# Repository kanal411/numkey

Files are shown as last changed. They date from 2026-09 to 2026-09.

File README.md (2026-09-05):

# Numkey
Functional external numerical keypad using only one keyboard switch on a H-bot kinematics.

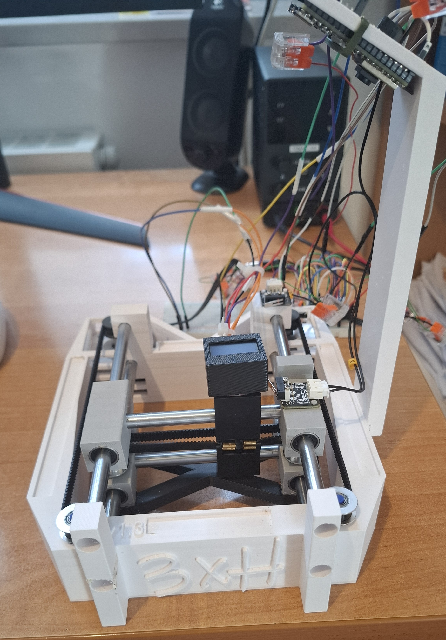
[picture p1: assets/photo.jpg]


## Features
- calibration process
- fully functional numlock
- H-bot kinematic
- sacrificial component

## How it works
An ESP32-S3 captures a photo of where your finger is, and then sends it to the connected PC via USB C. Then, a local neural network detects your finger, transforms its location on the photo to into coordinates above the device and moves the keyboard switch to the position of corresponding numpad key and updates the screen. When the ESP32 detects that the switch is pressed it sends that information to PC and a python script emulates keyboard inputs.

## Purpose
Main purpose of this project was for me to learn more about neural networks, controlling stepper motors and learning about different kinematics.

## Requirements
- Windows PC
- python 3
- arduino IDE (or other software to upload firmware to ESP32)

## How to make
### How to print:
  1. [`chassis.stl`](./models/chassis.stl) - ensure that chosen filament can withstand stepper motors temperatures, use low layer height/variable layer height, use organic supports.
  2. [`carriages.stl`](./models/carriages.stl) - use low layer height/variable layer height.
  3. [`sacrificial.stl`](./models/sacrificial.stl) - exact settings may need tuning for different printers, don't use more than 2 wall loops, use low infill (<=5%).
  4. [`rest.stl`](./models/rest.stl) - no supports.
### How to assemble:
  1. Assemble the parts as shown in [`assembly.mp4`](./assets/assembly.mp4).
  2. Install the timing belt.
  3. Upload [`ESP32_firmware.ino`](./code/ESP32_firmware.ino) to ESP32-S3.
  4. Connect all the wires accordingly to [`wiring.txt`](./assets/wiring.txt).
### How to use:
  1. Download all the files from [`code/`](./code/).
  2. Make sure that you have all of the packages listed in [`req.txt`](./req.txt).
  3. Plug the ESP32 into the PC via USB.
  4. Run [`main_code.py`](./code/main_code.py)

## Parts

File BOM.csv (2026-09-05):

item | quantity | price | note
ESP32-S3 + OV2640 | 1 | ~16$
0.96 OLED I2C 128x64 | 1 | ~2.5$
DR8825 | 2 | ~2$ x 2 | I recommend to buy it with radiator
LM8UU | 10 | ~1.3$ x 10
linear rail 8mm | 808cm | ~10$ | 2x 150cm, 2x 168cm, 2x 86cm
GT2 6mm timing pulley 5mm bore | 2 | ~2$ x2
GT2 6mm smooth pulley 5mm bore | 4 | ~2$ x4
GT2 6mm timing belt | 120cm | ~3$ | Exact lenght may vary
timing belt clamp | 2 | ~0.5$ x2
NEMA17 stepper motor | 2 | ~15$ x2 | I took them from ender 3 v2, if you use off-shelf then you have to buy a timing pulley for it
limit switch | 2 | ~2$ x2 | I took them from ender 3 v2
total |  | ~95.5$

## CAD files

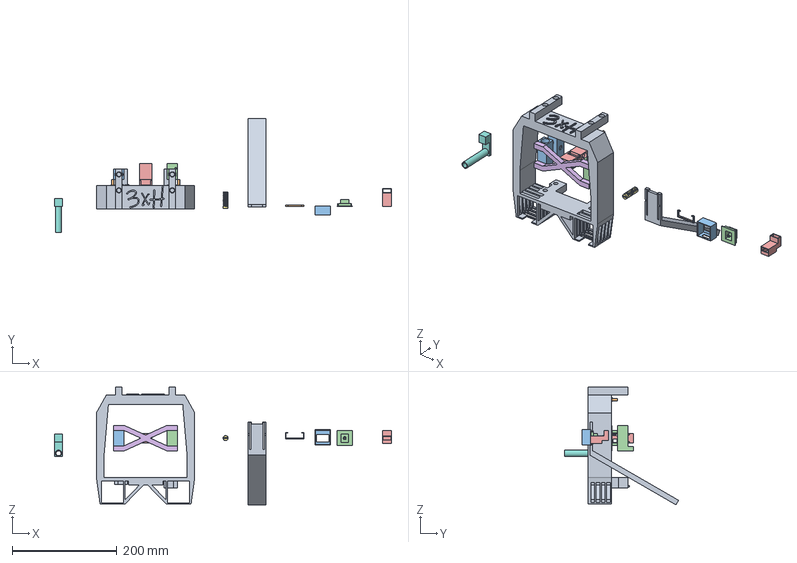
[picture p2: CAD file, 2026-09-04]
models/full_cad.step
644.1 x 218.3 x 225.0 mm

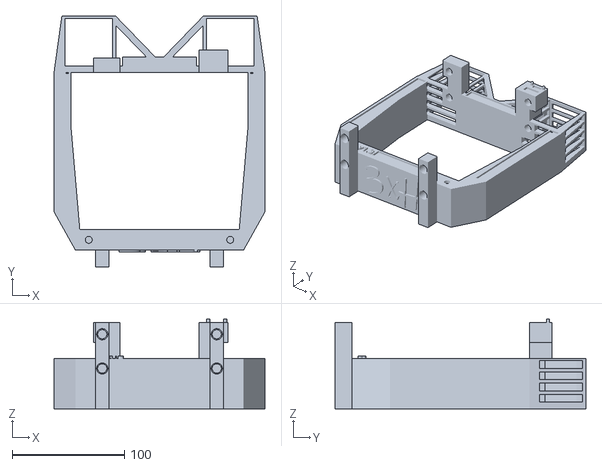
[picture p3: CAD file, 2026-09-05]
models/chassis.stl
188.0 x 223.2 x 80.0

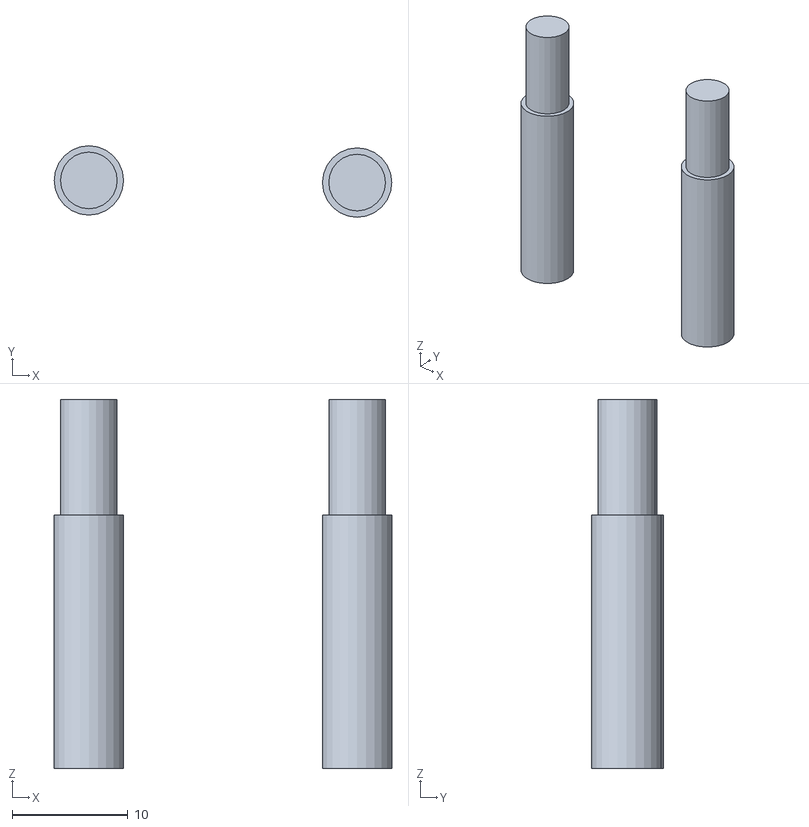
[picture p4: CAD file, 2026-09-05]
models/sacrificial.stl
29.2 x 6.19 x 31.9

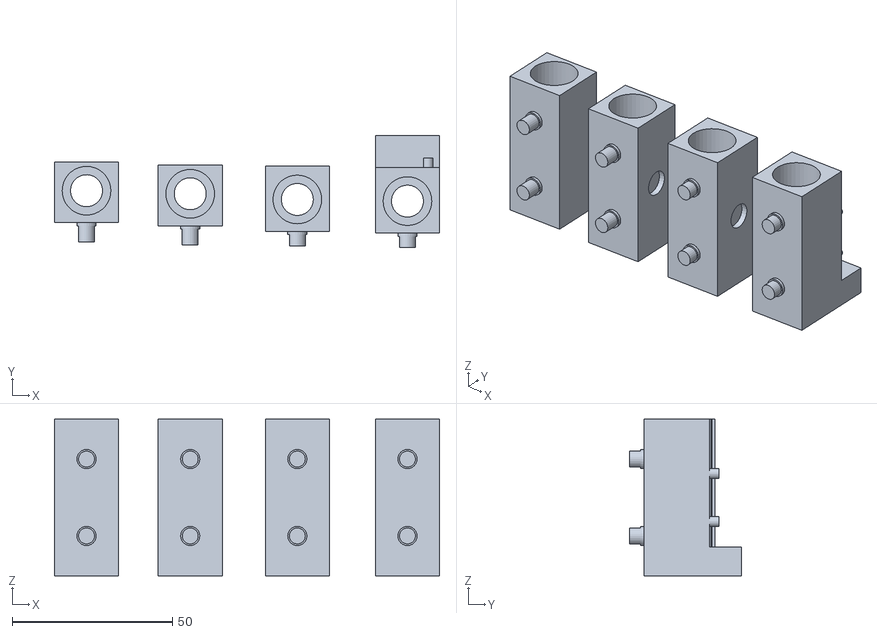
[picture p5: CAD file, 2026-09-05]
models/carriages.stl
120.2 x 35.0 x 49.0

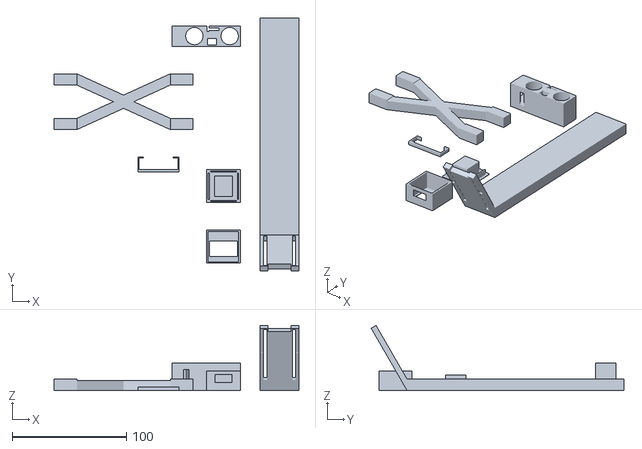
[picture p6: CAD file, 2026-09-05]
models/rest.stl
214.8 x 221.5 x 57.1

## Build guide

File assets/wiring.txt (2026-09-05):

OLED SDA - GPIO 48
OLED SCL - GPIO 47
X safety interlock - GPIO 14
Y safety interlock - GPIO 21
motor A dir - GPIO 2
motor A step - GPIO 1
motor B dir - GPIO 42
motor B step - GPIO 41

motor A/B EN - GND from ESP32
motor A/B M0 - 3.3V from ESP32
motor A/B M1 - 3.3V from ESP32
motor A/B M2 - 3.3V from ESP32
motor A/B RST - 3.3V from ESP32
motor A/B SLP - 3.3V from ESP32
motor A/B VMOT - 12V
motor A/B GN MOT - 12V supply GND
motor A/B B2 - stepper motor
motor A/B B1 - stepper motor
motor A/B A1 - stepper motor
motor A/B A2 - stepper motor
motor A/B GND LOGIC -ESP32 GND

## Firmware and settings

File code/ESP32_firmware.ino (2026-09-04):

#include "esp_camera.h"
#include "esp_task_wdt.h"
#include <Wire.h>
#include <Adafruit_GFX.h>
#include <Adafruit_SSD1306.h>

#define OLED_W    128
#define OLED_H    64
#define OLED_ADDR 0x3C
#define OLED_SDA  48
#define OLED_SCL  47

Adafruit_SSD1306 display(OLED_W, OLED_H, &Wire, -1);
bool oledReady = false;

#define MAX_TEXT_LEN 128

#define BUTTON_PIN          40
#define BUTTON_ACTIVE_HIGH  true
#define BUTTON_DEBOUNCE_MS  30

#define USE_AUTO_EXPOSURE   false
#define EXPOSURE_VALUE      130
#define GAIN_VALUE          12

static const uint8_t SYNC0 = 0xA5;
static const uint8_t SYNC1 = 0x5A;
static const uint8_t TYPE_FRAME    = 0x01;
static const uint8_t TYPE_COORDS   = 0x02;
static const uint8_t TYPE_TARGET   = 0x03;
static const uint8_t TYPE_ARRIVED  = 0x04;
static const uint8_t TYPE_HOME     = 0x05;
static const uint8_t TYPE_STREAM   = 0x06;
static const uint8_t TYPE_STATUS   = 0x07;
static const uint8_t TYPE_EXPOSURE = 0x08;
static const uint8_t TYPE_TEXT     = 0x09;
static const uint8_t TYPE_BUTTON   = 0x0A;

static const uint8_t ST_NOT_HOMED = 0;
static const uint8_t ST_HOMING    = 1;
static const uint8_t ST_HOMED     = 2;
static const uint8_t ST_FAILED    = 3;

uint8_t crc8(const uint8_t *data, size_t len) {
  uint8_t c = 0x00;
  for (size_t i = 0; i < len; i++) {
    c ^= data[i];
    for (uint8_t b = 0; b < 8; b++)
      c = (c & 0x80) ? (uint8_t)((c << 1) ^ 0x07) : (uint8_t)(c << 1);
  }
  return c;
}

#define PWDN_GPIO_NUM     -1
#define RESET_GPIO_NUM    -1
#define XCLK_GPIO_NUM     15
#define SIOD_GPIO_NUM     4
#define SIOC_GPIO_NUM     5
#define Y9_GPIO_NUM       16
#define Y8_GPIO_NUM       17
#define Y7_GPIO_NUM       18
#define Y6_GPIO_NUM       12
#define Y5_GPIO_NUM       10
#define Y4_GPIO_NUM       8
#define Y3_GPIO_NUM       9
#define Y2_GPIO_NUM       11
#define VSYNC_GPIO_NUM    6
#define HREF_GPIO_NUM     7
#define PCLK_GPIO_NUM     13
#define FRAME_SIZE        FRAMESIZE_VGA
#define JPEG_QUALITY      12          // nizsza liczba = lepsza jakosc (0-63)
#define DEBUG_EVERY_N     30

const bool INVERT_DIR_A = false;
const bool INVERT_DIR_B = false;

const int dirA = 2;
const int stepA = 1;
const int dirB = 42;
const int stepB = 41;
const int buttonX = 14;
const int buttonY = 21;

const float homingJump = 150.0f;
const float unhomingJump = 300.0f;
const float homingJumpPrecise = 3.0f;
const int homingPause = 0;

const float SPEED_MIN = 80.0f;
const float SPEED_MAX = 80000.0f;
const float ACCEL_MAX = 500000.0f;

const float maxX = 7750;
const float maxY = 12700;

long posA = 0;
long posB = 0;
float posX;
float posY;
float ACCEL = ACCEL_MAX;

portMUX_TYPE targetMux = portMUX_INITIALIZER_UNLOCKED;
volatile float targetX = 0.0f;
volatile float targetY = 0.0f;
volatile uint32_t targetVersion = 0;

volatile bool arrivedFlag = false;

float refX = 0.0f, refY = 0.0f;
long refA = 0, refB = 0;

bool homed = false;
uint8_t homingState = ST_NOT_HOMED;
bool motionTaskStarted = false;

uint32_t frameId = 0;
bool streaming = false;

volatile bool     fingerFound   = false;
volatile uint16_t fingerX       = 0;
volatile uint16_t fingerY       = 0;
volatile uint32_t coordsFrameId = 0;
volatile uint32_t coordsCount   = 0;

void onFingerCoords(uint32_t id, bool found, uint16_t x, uint16_t y) {
  fingerFound   = found;
  fingerX       = x;
  fingerY       = y;
  coordsFrameId = id;
  coordsCount++;
}

static inline float axisX() { return refX + 0.5f * (float)((posA - refA) - (posB - refB)); }
static inline float axisY() { return refY + 0.5f * (float)((posA - refA) + (posB - refB)); }

void setTarget(float x, float y) {
  if (x < 0) x = 0;
  if (x > maxX) x = maxX;
  if (y < 0) y = 0;
  if (y > maxY) y = maxY;
  portENTER_CRITICAL(&targetMux);
  targetX = x;
  targetY = y;
  targetVersion++;
  portEXIT_CRITICAL(&targetMux);
}

void getTarget(float *x, float *y, uint32_t *ver) {
  portENTER_CRITICAL(&targetMux);
  *x = targetX;
  *y = targetY;
  *ver = targetVersion;
  portEXIT_CRITICAL(&targetMux);
}

void sendStatus() {
  uint8_t sw = 0;
  if (digitalRead(buttonX)) sw |= 0x01;
  if (digitalRead(buttonY)) sw |= 0x02;
  uint8_t body[3] = { TYPE_STATUS, homingState, sw };
  uint8_t pkt[6] = { SYNC0, SYNC1, body[0], body[1], body[2], crc8(body, 3) };
  Serial.write(pkt, sizeof(pkt));
}

void sendArrived() {
  uint16_t x = (uint16_t)lroundf(posX);
  uint16_t y = (uint16_t)lroundf(posY);
  uint8_t body[5] = { TYPE_ARRIVED,
                      (uint8_t)(x & 0xFF), (uint8_t)(x >> 8),
                      (uint8_t)(y & 0xFF), (uint8_t)(y >> 8) };
  uint8_t pkt[8] = { SYNC0, SYNC1, body[0], body[1], body[2], body[3], body[4],
                     crc8(body, 5) };
  Serial.write(pkt, sizeof(pkt));
}

uint16_t layoutText(const char *text, uint8_t size, bool draw, int16_t yOff) {
  const uint8_t cols = OLED_W / (6 * size);
  const uint8_t rows = OLED_H / (8 * size);
  uint16_t line = 0;
  uint16_t i = 0;

  while (text[i] != '\0') {
    while (text[i] == ' ') i++;
    if (text[i] == '\0') break;
    if (text[i] == '\n') { i++; line++; continue; }

    uint16_t start = i;
    uint16_t lastSpace = 0;
    bool haveSpace = false;
    uint8_t n = 0;

    while (text[i] != '\0' && text[i] != '\n' && n < cols) {
      if (text[i] == ' ') { lastSpace = i; haveSpace = true; }
      i++;
      n++;
    }

    uint16_t end = i;
    if (text[i] != '\0' && text[i] != '\n' && haveSpace) {
      end = lastSpace;
      i = lastSpace + 1;
    }

    if (draw && line < rows) {
      display.setCursor(0, yOff + (int16_t)line * 8 * size);
      for (uint16_t k = start; k < end; k++) display.write(text[k]);
    }
    line++;
    if (text[i] == '\n') i++;
  }
  return line;
}

void showText(const char *text) {
  if (!oledReady) return;

  display.clearDisplay();
  display.setTextColor(SSD1306_WHITE);
  display.setTextWrap(false);

  uint8_t size = 2;
  if (layoutText(text, 2, false, 0) > OLED_H / (8 * 2)) size = 1;

  display.setTextSize(size);
  uint16_t lines = layoutText(text, size, false, 0);
  uint8_t rows = OLED_H / (8 * size);
  int16_t yOff = 0;
  if (lines < rows) yOff = ((int16_t)rows - (int16_t)lines) * 8 * size / 2;

  layoutText(text, size, true, yOff);
  display.display();
}

void setupOled() {
  Wire.begin(OLED_SDA, OLED_SCL);
  Wire.setClock(400000);
  oledReady = display.begin(SSD1306_SWITCHCAPVCC, OLED_ADDR);
  if (!oledReady) {
    Serial0.printf("OLED: brak odpowiedzi pod adresem 0x%02X (SDA=%d SCL=%d).\n",
                   OLED_ADDR, OLED_SDA, OLED_SCL);
    Serial0.println("Sprawdz okablowanie i adres. Reszta firmware dziala normalnie.");
    return;
  }
  display.clearDisplay();
  display.display();
  Serial0.println("OLED gotowy.");
}

void sendButton() {
  uint16_t x = (uint16_t)lroundf(posX);
  uint16_t y = (uint16_t)lroundf(posY);
  uint8_t body[5] = { TYPE_BUTTON,
                      (uint8_t)(x & 0xFF), (uint8_t)(x >> 8),
                      (uint8_t)(y & 0xFF), (uint8_t)(y >> 8) };
  uint8_t pkt[8] = { SYNC0, SYNC1, body[0], body[1], body[2], body[3], body[4],
                     crc8(body, 5) };
  Serial.write(pkt, sizeof(pkt));
}

void pollButton() {
  static bool lastPressed = false;
  static uint32_t lockoutUntil = 0;

  uint32_t now = millis();
  if ((int32_t)(now - lockoutUntil) < 0) return;

  bool pressed = (digitalRead(BUTTON_PIN) == HIGH) == BUTTON_ACTIVE_HIGH;
  if (pressed == lastPressed) return;

  lastPressed = pressed;
  lockoutUntil = now + BUTTON_DEBOUNCE_MS;
  if (pressed) {
    sendButton();
    Serial0.printf("Przycisk: wcisniety przy X=%.0f Y=%.0f\n", posX, posY);
  }
}

void applyExposure(uint16_t aec, uint8_t gain) {
  sensor_t *s = esp_camera_sensor_get();
  if (!s) { Serial0.println("Brak uchwytu sensora."); return; }

  if (aec == 0xFFFF) {
    s->set_exposure_ctrl(s, 1);
    s->set_aec2(s, 1);
    s->set_gain_ctrl(s, 1);
    Serial0.println("Naswietlanie: AUTO");
  } else {
    if (aec > 1200) aec = 1200;
    if (gain > 30) gain = 30;
    s->set_exposure_ctrl(s, 0);
    s->set_aec2(s, 0);
    s->set_gain_ctrl(s, 0);
    s->set_aec_value(s, aec);
    s->set_agc_gain(s, gain);
    Serial0.printf("Naswietlanie: RECZNE aec=%u gain=%u\n", aec, gain);
  }
}

void stepPulse(uint8_t pin) {
  digitalWrite(pin, HIGH);
  delayMicroseconds(4);
  digitalWrite(pin, LOW);
}

void moveAB(long dA, long dB) {
  digitalWrite(dirA, ((dA >= 0) != INVERT_DIR_A) ? HIGH : LOW);
  digitalWrite(dirB, ((dB >= 0) != INVERT_DIR_B) ? HIGH : LOW);
  delayMicroseconds(10);

  long aA = labs(dA);
  long aB = labs(dB);
  long total = (aA > aB) ? aA : aB;
  if (total == 0) return;

  long slave = (aA < aB) ? aA : aB;
  bool aIsMaster = (aA >= aB);
  long err = total / 2;

  int sgnA = (dA > 0) ? 1 : -1;
  int sgnB = (dB > 0) ? 1 : -1;

  for (long i = 0; i < total; i++) {
    float vAcc = sqrtf(SPEED_MIN * SPEED_MIN + 2.0f * ACCEL * (float)i);
    float vDec = sqrtf(SPEED_MIN * SPEED_MIN + 2.0f * ACCEL * (float)(total - i));
    float v = vAcc;
    if (vDec < v) v = vDec;
    if (SPEED_MAX < v) v = SPEED_MAX;
    unsigned long interval = (unsigned long)(1000000.0f / v);

    if (aIsMaster) {
      stepPulse(stepA);
      posA += sgnA;
      err -= slave;
      if (err < 0) { err += total; stepPulse(stepB); posB += sgnB; }
    } else {
      stepPulse(stepB);
      posB += sgnB;
      err -= slave;
      if (err < 0) { err += total; stepPulse(stepA); posA += sgnA; }
    }

    delayMicroseconds(interval);
  }
}

void moveToolhead(float x, float y, bool pominacOgraniczenia = false) {
  if ((posX + x < 0 || posX + x > maxX || posY + y < 0 || posY + y > maxY) && !pominacOgraniczenia)
  {
    Serial0.println("Incorrect coordinates.");
    return;
  }
  posX += x;
  posY += y;
  moveAB(y + x, y - x);
}

float runSegment(long dA, long dB, float vEntry, uint32_t *seenVer) {
  digitalWrite(dirA, ((dA >= 0) != INVERT_DIR_A) ? HIGH : LOW);
  digitalWrite(dirB, ((dB >= 0) != INVERT_DIR_B) ? HIGH : LOW);
  delayMicroseconds(10);

  long aA = labs(dA);
  long aB = labs(dB);
  long total = (aA > aB) ? aA : aB;
  if (total == 0) return SPEED_MIN;

  long slave = (aA < aB) ? aA : aB;
  bool aIsMaster = (aA >= aB);
  long err = total / 2;

  int sgnA = (dA > 0) ? 1 : -1;
  int sgnB = (dB > 0) ? 1 : -1;

  float v = (vEntry > SPEED_MIN) ? vEntry : SPEED_MIN;
  bool stopping = false;

  for (long i = 0; i < total; i++) {
    long remaining = total - i;

    float vStop = sqrtf(SPEED_MIN * SPEED_MIN + 2.0f * ACCEL * (float)remaining);
    float dt = 1.0f / v;
    float vNext;
    if (stopping) {
      vNext = v - ACCEL * dt;
    } else {
      vNext = v + ACCEL * dt;
      if (vNext > SPEED_MAX) vNext = SPEED_MAX;
    }
    if (vNext > vStop) vNext = vStop;
    if (vNext < SPEED_MIN) vNext = SPEED_MIN;
    v = vNext;

    if (aIsMaster) {
      stepPulse(stepA);
      posA += sgnA;
      err -= slave;
      if (err < 0) { err += total; stepPulse(stepB); posB += sgnB; }
    } else {
      stepPulse(stepB);
      posB += sgnB;
      err -= slave;
      if (err < 0) { err += total; stepPulse(stepA); posA += sgnA; }
    }

    delayMicroseconds((unsigned long)(1000000.0f / v));

    if (stopping && v <= SPEED_MIN + 0.5f) return SPEED_MIN;

    if (*seenVer != targetVersion) {
      float tx, ty;
      uint32_t ver;
      getTarget(&tx, &ty, &ver);
      *seenVer = ver;

      float cx = axisX();
      float cy = axisY();
      long ndA = lroundf((ty - cy) + (tx - cx));
      long ndB = lroundf((ty - cy) - (tx - cx));
      long nTotal = (labs(ndA) > labs(ndB)) ? labs(ndA) : labs(ndB);

      bool dirOkA = (aA == 0) || (ndA == 0) || (((ndA > 0) ? 1 : -1) == sgnA);
      bool dirOkB = (aB == 0) || (ndB == 0) || (((ndB > 0) ? 1 : -1) == sgnB);
      bool feasible = (nTotal > 0) &&
                      (v * v <= SPEED_MIN * SPEED_MIN + 2.0f * ACCEL * (float)nTotal);

      if (dirOkA && dirOkB && feasible) {
        return v;
      } else {
        stopping = true;
      }
    }
  }
  return v;
}

void motionTask(void *arg) {
  uint32_t ver;
  {
    float tx, ty;
    getTarget(&tx, &ty, &ver);
  }
  float v = SPEED_MIN;
  bool announced = false;

  for (;;) {
    float tx, ty;
    getTarget(&tx, &ty, &ver);

    long dA = lroundf((ty - axisY()) + (tx - axisX()));
    long dB = lroundf((ty - axisY()) - (tx - axisX()));

    if (dA == 0 && dB == 0) {
      v = SPEED_MIN;
      posX = axisX();
      posY = axisY();
      if (!announced) {
        announced = true;
        arrivedFlag = true;
      }
      vTaskDelay(1);
      continue;
    }

    announced = false;
    v = runSegment(dA, dB, v, &ver);
    posX = axisX();
    posY = axisY();
  }
}

void runHoming() {
  homingState = ST_HOMING;
  sendStatus();

  Serial0.printf("Homing start. Krancowki: X=%d Y=%d\n",
                 digitalRead(buttonX), digitalRead(buttonY));

  ACCEL = 30000;
  
  long searchLoops = 0;

  while (digitalRead(buttonX) == LOW) {
    moveToolhead(homingJump, 0.0f, true);
    delayMicroseconds(homingPause);
    searchLoops++;
    yield();
  }
  moveToolhead(-unhomingJump, 0.0f, true);
  Serial0.println("Homed x axis.");

  while (digitalRead(buttonY) == LOW) {
    moveToolhead(0.0f, homingJump, true);
    delayMicroseconds(homingPause);
    searchLoops++;
    yield();
  }
  Serial0.println("Homed y axis.");
  moveToolhead(0.0f, -unhomingJump, true);

  while (digitalRead(buttonX) == LOW) {
    moveToolhead(homingJumpPrecise, 0.0f, true);
    delayMicroseconds(homingPause);
    searchLoops++;
    yield();
  }
  Serial0.println("Finished correcting x axis.");

  while (digitalRead(buttonY) == LOW) {
    moveToolhead(0.0f, homingJumpPrecise, true);
    delayMicroseconds(homingPause);
    searchLoops++;
    yield();
  }
  Serial0.println("Finished homing.");
  moveToolhead(-unhomingJump, -unhomingJump, true);

  ACCEL = ACCEL_MAX;
  
  if (searchLoops == 0) {
    homingState = ST_FAILED;
    homed = false;
    Serial0.println("BLAD HOMINGU: zadna petla szukania sie nie wykonala.");
    Serial0.printf("Odczyt krancowek: buttonX=%d buttonY=%d\n",
                   digitalRead(buttonX), digitalRead(buttonY));
    Serial0.println("Sprawdz podlaczenie i logike (NO/NC) przelacznikow.");
    sendStatus();
    return;
  }

  posX = maxX;
  posY = maxY;
  refX = posX;  refY = posY;
  refA = posA;  refB = posB;
  setTarget(posX, posY);

#if ESP_IDF_VERSION_MAJOR >= 5
  esp_task_wdt_config_t twdt_cfg = {
    .timeout_ms = 10000,
    .idle_core_mask = (1 << 1),
    .trigger_panic = false
  };
  esp_task_wdt_reconfigure(&twdt_cfg);
#else
  disableCore0WDT();
#endif

  if (!motionTaskStarted) {
    xTaskCreatePinnedToCore(motionTask, "motion", 8192, NULL, 2, NULL, 0);
    motionTaskStarted = true;
  }

  homed = true;
  homingState = ST_HOMED;
  Serial0.printf("Homing OK (%ld obrotow petli szukania). Silnik ruchu na core 0.\n",
                 searchLoops);
  sendStatus();
}

void setupCamera() {
  camera_config_t config;
  config.ledc_channel = LEDC_CHANNEL_0;
  config.ledc_timer   = LEDC_TIMER_0;
  config.pin_d0 = Y2_GPIO_NUM;
  config.pin_d1 = Y3_GPIO_NUM;
  config.pin_d2 = Y4_GPIO_NUM;
  config.pin_d3 = Y5_GPIO_NUM;
  config.pin_d4 = Y6_GPIO_NUM;
  config.pin_d5 = Y7_GPIO_NUM;
  config.pin_d6 = Y8_GPIO_NUM;
  config.pin_d7 = Y9_GPIO_NUM;
  config.pin_xclk = XCLK_GPIO_NUM;
  config.pin_pclk = PCLK_GPIO_NUM;
  config.pin_vsync = VSYNC_GPIO_NUM;
  config.pin_href = HREF_GPIO_NUM;
  config.pin_sccb_sda = SIOD_GPIO_NUM;
  config.pin_sccb_scl = SIOC_GPIO_NUM;
  config.pin_pwdn = PWDN_GPIO_NUM;
  config.pin_reset = RESET_GPIO_NUM;
  config.xclk_freq_hz = 20000000;
  config.pixel_format = PIXFORMAT_JPEG;
  config.grab_mode    = CAMERA_GRAB_LATEST;
  config.fb_location  = CAMERA_FB_IN_PSRAM;

  if (psramFound()) {
    config.frame_size   = FRAME_SIZE;
    config.jpeg_quality = JPEG_QUALITY;
    config.fb_count     = 2;
  } else {
    Serial0.println("UWAGA: brak PSRAM! Wlacz OPI PSRAM w Tools.");
    config.frame_size   = FRAMESIZE_QVGA;
    config.jpeg_quality = 15;
    config.fb_count     = 1;
  }

  esp_err_t err = esp_camera_init(&config);
  if (err != ESP_OK) {
    Serial0.printf("BLAD INICJALIZACJI KAMERY: 0x%x\n", err);
    while (true) { delay(1000); }
  }
  Serial0.println("Kamera OK");

#if USE_AUTO_EXPOSURE
  applyExposure(0xFFFF, 0);
#else
  applyExposure(EXPOSURE_VALUE, GAIN_VALUE);
#endif
}

#define MAX_FPS               18
#define MIN_FRAME_INTERVAL_MS (1000 / MAX_FPS)

#define FRAME_TX_TIMEOUT_MS   400

uint32_t framesDropped = 0;

bool writeAll(const uint8_t *data, size_t len) {
  size_t sent = 0;
  uint32_t t0 = millis();
  while (sent < len) {
    size_t n = Serial.write(data + sent, len - sent);
    if (n > 0) {
      sent += n;
      t0 = millis();
    } else {
      if (millis() - t0 > FRAME_TX_TIMEOUT_MS) return false;
      delay(1);
    }
  }
  return true;
}

void sendFrame(camera_fb_t *fb) {
  uint8_t header[11];
  header[0] = SYNC0;
  header[1] = SYNC1;
  header[2] = TYPE_FRAME;
  header[3] = (uint8_t)(frameId        & 0xFF);
  header[4] = (uint8_t)((frameId >> 8)  & 0xFF);
  header[5] = (uint8_t)((frameId >> 16) & 0xFF);
  header[6] = (uint8_t)((frameId >> 24) & 0xFF);
  uint32_t len = fb->len;
  header[7]  = (uint8_t)(len        & 0xFF);
  header[8]  = (uint8_t)((len >> 8)  & 0xFF);
  header[9]  = (uint8_t)((len >> 16) & 0xFF);
  header[10] = (uint8_t)((len >> 24) & 0xFF);

  if (Serial.availableForWrite() < (int)sizeof(header)) {
    framesDropped++;
    return;
  }

  if (!writeAll(header, sizeof(header)) || !writeAll(fb->buf, fb->len)) {
    framesDropped++;
  }
}

void pollRx() {
  static uint8_t buf[4 + MAX_TEXT_LEN];
  static uint16_t pos = 0;
  static uint16_t need = 0;

  while (Serial.available()) {
    uint8_t b = (uint8_t)Serial.read();

    if (pos == 0) {
      if (b == SYNC0) buf[pos++] = b;
    } else if (pos == 1) {
      if (b == SYNC1) buf[pos++] = b;
      else pos = (b == SYNC0) ? 1 : 0;
    } else if (pos == 2) {
      if (b == TYPE_COORDS)        { buf[pos++] = b; need = 12; }
      else if (b == TYPE_TARGET)   { buf[pos++] = b; need = 7;  }
      else if (b == TYPE_STREAM)   { buf[pos++] = b; need = 4;  }
      else if (b == TYPE_EXPOSURE) { buf[pos++] = b; need = 6;  }
      else if (b == TYPE_TEXT)     { buf[pos++] = b; need = 0;  }
      else if (b == TYPE_HOME)     {
        pos = 0;
        if (!homed) runHoming();
        else { sendStatus(); sendArrived(); }
      }
      else pos = (b == SYNC0) ? 1 : 0;
    } else {
      if (pos < sizeof(buf)) buf[pos] = b;
      pos++;

      if (buf[2] == TYPE_TEXT && pos == 4) {
        need = 4 + (uint16_t)buf[3];
      }

      if (need != 0 && pos == need) {
        if (buf[2] == TYPE_COORDS) {
          uint32_t id = (uint32_t)buf[3] | ((uint32_t)buf[4] << 8) |
                        ((uint32_t)buf[5] << 16) | ((uint32_t)buf[6] << 24);
          bool     found = buf[7] != 0;
          uint16_t x = (uint16_t)buf[8]  | ((uint16_t)buf[9]  << 8);
          uint16_t y = (uint16_t)buf[10] | ((uint16_t)buf[11] << 8);
          onFingerCoords(id, found, x, y);
        } else if (buf[2] == TYPE_TARGET) {
          uint16_t x = (uint16_t)buf[3] | ((uint16_t)buf[4] << 8);
          uint16_t y = (uint16_t)buf[5] | ((uint16_t)buf[6] << 8);
          if (homed) setTarget((float)x, (float)y);
          else { Serial0.println("TARGET zignorowany: brak homingu."); sendStatus(); }
        } else if (buf[2] == TYPE_STREAM) {
          streaming = (buf[3] != 0);
          Serial0.printf("Strumien klatek: %s\n", streaming ? "ON" : "OFF");
        } else if (buf[2] == TYPE_EXPOSURE) {
          uint16_t aec = (uint16_t)buf[3] | ((uint16_t)buf[4] << 8);
          applyExposure(aec, buf[5]);
        } else if (buf[2] == TYPE_TEXT) {
          uint16_t n = buf[3];
          if (n > MAX_TEXT_LEN) n = MAX_TEXT_LEN;
          char txt[MAX_TEXT_LEN + 1];
          memcpy(txt, buf + 4, n);
          txt[n] = '\0';
          showText(txt);
          Serial0.printf("OLED: \"%s\"\n", txt);
        }
        pos = 0;
        need = 0;
      }
    }
  }
}

void setup() {
  Serial.begin(115200);
  Serial.setTxTimeoutMs(FRAME_TX_TIMEOUT_MS);
  Serial0.begin(115200);
  delay(500);
  Serial0.println("\n=== ESP32-S3 finger cam + CNC (protokol v3) ===");

  pinMode(dirA, OUTPUT);
  pinMode(stepA, OUTPUT);
  pinMode(dirB, OUTPUT);
  pinMode(stepB, OUTPUT);
  pinMode(buttonX, INPUT_PULLUP);
  pinMode(buttonY, INPUT_PULLUP);
  pinMode(BUTTON_PIN, BUTTON_ACTIVE_HIGH ? INPUT_PULLDOWN : INPUT_PULLUP);
  digitalWrite(stepA, LOW);
  digitalWrite(stepB, LOW);
  digitalWrite(dirA, LOW);
  digitalWrite(dirB, LOW);
  setupOled();

  setupCamera();

  Serial0.printf("Krancowki po starcie: buttonX=%d buttonY=%d\n",
                 digitalRead(buttonX), digitalRead(buttonY));
  Serial0.println("Strumien klatek WYLACZONY. Czekam na komendy z PC.");
}

void loop() {
  pollRx();
  pollButton();

  if (arrivedFlag) {
    arrivedFlag = false;
    sendArrived();
  }

  if (!streaming) {
    delay(2);
    return;
  }
  static uint32_t lastFrameMs = 0;
  uint32_t nowMs = millis();
  if (nowMs - lastFrameMs < MIN_FRAME_INTERVAL_MS) {
    delay(1);
    return;
  }
  lastFrameMs = nowMs;

  camera_fb_t *fb = esp_camera_fb_get();
  if (fb) {
    sendFrame(fb);
    esp_camera_fb_return(fb);
    frameId++;
  }

  static uint32_t t0 = millis();
  if (frameId > 0 && frameId % DEBUG_EVERY_N == 0) {
    uint32_t now = millis();
    if (now - t0 > 500) {
      float fps = DEBUG_EVERY_N * 1000.0f / (float)(now - t0);
      t0 = now;
      Serial0.printf("TX fps=%.1f | porzucone=%lu | odp=%lu | palec: found=%d x=%u y=%u "
                     "| CNC: X=%.0f Y=%.0f\n",
                     fps, (unsigned long)framesDropped, (unsigned long)coordsCount,
                     (int)fingerFound, fingerX, fingerY, posX, posY);
    }
  }
}

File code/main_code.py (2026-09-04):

import time
import cv2
import numpy as np
from finger_api import FingerRig
import button_click
import kalibracja

def clamp(value, min_value, max_value):
    return max(min(value, max_value), min_value)

numpadKeys = [
    ["menu", "/", "*", "-"],
    ["7", "8", "9", "+"],
    ["4", "5", "6", "+"],
    ["1", "2", "3", "enter"],
    ["0", "0", ".", "enter"]
]


def pytaj_o_kalibracje(rig, sekundy=2.0):
    rig.displayText("recalibrate?")
    rig.clear_button_presses()
    koniec = time.monotonic() + sekundy
    while time.monotonic() < koniec:
        if rig.button_pressed():
            return True
        rig.wait(0.05)
    return False


def wykonaj_kalibracje(rig):
    rogi = [[[-1, -1], [-1, -1]], [[-1, -1], [-1, -1]]]

    rig.displayText("Keep your finger above the key.")
    rig.move_to(0, 0)
    time.sleep(10)
    print("smile")
    rog = rig.read_finger(True, 3.0, True, True)
    rog.found = False
    while not rog.found:
        rog = rig.read_finger(True, 3.0, True, True)
        if rog.found:
            rogi[0][1][0], rogi[0][1][1] = rog.x, rog.y
        else:
            rig.move_to(3875, 6350)
            time.sleep(1)
            rig.move_to(0, 0)
            time.sleep(4)
    rig.move_to(7750, 0)
    time.sleep(4)
    print("smile")
    rog = rig.read_finger(True, 3.0, True, True)
    rog.found = False
    while not rog.found:
        rog = rig.read_finger(True, 3.0, True, True)
        if rog.found:
            rogi[1][1][0], rogi[1][1][1] = rog.x, rog.y
        else:
            rig.move_to(3875, 6350)
            time.sleep(1)
            rig.move_to(7750, 0)
            time.sleep(4)
    rig.move_to(7750, 12700)
    time.sleep(4)
    print("smile")
    rog = rig.read_finger(True, 3.0, True, True)
    rog.found = False
    while not rog.found:
        rog = rig.read_finger(True, 3.0, True, True)
        if rog.found:
            rogi[1][0][0], rogi[1][0][1] = rog.x, rog.y
        else:
            rig.move_to(3875, 6350)
            time.sleep(1)
            rig.move_to(7750, 12700)
            time.sleep(4)
    rig.move_to(0, 12700)
    time.sleep(4)
    print("smile")
    rog = rig.read_finger(True, 3.0, True, True)
    rog.found = False
    while not rog.found:
        rog = rig.read_finger(True, 3.0, True, True)
        if rog.found:
            rogi[0][0][0], rogi[0][0][1] = rog.x, rog.y
        else:
            rig.move_to(3875, 6350)
            time.sleep(1)
            rig.move_to(0, 12700)
            time.sleep(4)
    print("Calculating. Please wait...")                                                                   
    rig.displayText("Please wait...")

    finger_borders = np.float32([
    rogi[0][0],
    rogi[1][0],
    rogi[1][1],
    rogi[0][1]
    ])

    plane_points = np.float32([
        [0, 12700],
        [7750, 12700],
        [7750, 0],
        [0, 0]
    ])

    H, _ = cv2.findHomography(finger_borders, plane_points)
    return H


with FingerRig(on_demand=True) as rig:
    print("Starting homing sequence.")
    rig.displayText("Homing...")
    rig.home()

    H = kalibracja.wczytaj()
    if H is not None and pytaj_o_kalibracje(rig):
        print("Zlecono ponowna kalibracje.")
        H = None
    if H is None:
        H = wykonaj_kalibracje(rig)
        kalibracja.zapisz(H)

    print("Working.")
    rig.displayText("")

    rig.clear_button_presses()

    rig.on_button(lambda x, y: button_click.run(rig, (x, y)))

    aktualnyTekst = "placeholder"
    rig.displayText("Working...")
    while True:
        while rig.busy:
            time.sleep(0.1)

        if button_click.kalibracja_zadana():
            rig.on_button(None)
            H = wykonaj_kalibracje(rig)
            kalibracja.zapisz(H)
            rig.clear_button_presses()
            rig.on_button(lambda x, y: button_click.run(rig, (x, y)))
            print("Working.")
            rig.displayText("Working...")
            continue

        if button_click.zawieszony():
            rig.wait(0.2)
            continue

        palec = rig.read_finger()

        if button_click.zawieszony():
            continue

        if palec.found:
            pixel = np.array([
                [[palec.x, palec.y]]
            ], dtype=np.float32)

            plane_point = cv2.perspectiveTransform(pixel, H)

            finX, finY = plane_point[0][0]

            finX = clamp(finX, 0, 7750)
            finY = clamp(finY, 0, 12700)

            uklad = button_click.aktywny_uklad(numpadKeys)
            wierszy = len(uklad)
            kolumn = len(uklad[0])
            szerKol = 7750 / kolumn
            wysWier = 12700 / wierszy

            kol = clamp(int(finX // szerKol), 0, kolumn - 1)
            wier = clamp(int(finY // wysWier), 0, wierszy - 1)

            wierszTablicy = (wierszy - 1) - wier
            klawisz = uklad[wierszTablicy][kol]

            if klawisz is None:
                continue
            if klawisz != rig.displayed_text:
                rig.displayText(klawisz)

            kolOd = kolDo = kol
            while kolOd > 0 and uklad[wierszTablicy][kolOd - 1] == klawisz:
                kolOd -= 1
            while kolDo < kolumn - 1 and uklad[wierszTablicy][kolDo + 1] == klawisz:
                kolDo += 1

            wierOd = wierDo = wierszTablicy
            while wierOd > 0 and uklad[wierOd - 1][kol] == klawisz:
                wierOd -= 1
            while wierDo < wierszy - 1 and uklad[wierDo + 1][kol] == klawisz:
                wierDo += 1

            celX = (kolOd + kolDo + 1) / 2 * szerKol
            celY = ((wierszy - 1 - wierDo) + (wierszy - 1 - wierOd) + 1) / 2 * wysWier

            rig.move_to(celX, celY)
        else:
            rig.wait(0.1)

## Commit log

2026-09-04 3d models
    [full_cad.step]
2026-09-05 Bill Of Materials
    [BOM.csv]
